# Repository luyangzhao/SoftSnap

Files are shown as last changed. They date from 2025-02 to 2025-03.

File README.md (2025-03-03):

# **SoftSnap: A Modular and Untethered Soft Robotics Platform**  

## 🚀 Overview  
SoftSnap is a **modular, untethered soft robotics system** designed for **rapid prototyping** and exploration of **bio-inspired locomotion and manipulation tasks**. It enables researchers, educators, and hobbyists to quickly assemble **snap-together robotic modules** with integrated **cable-driven actuation, onboard control, and wireless communication**.

### **🎥 Demonstration Video**  
Watch the SoftSnap in action:  
SoftSnap Video (https://www.youtube.com/watch?v=SWuYzo7xSno)

---

### **🔹 SoftSnap Full Assembly**
<!-- ![SoftSnap Full Assembly](hardware/cad/softsnap_module.png)   -->
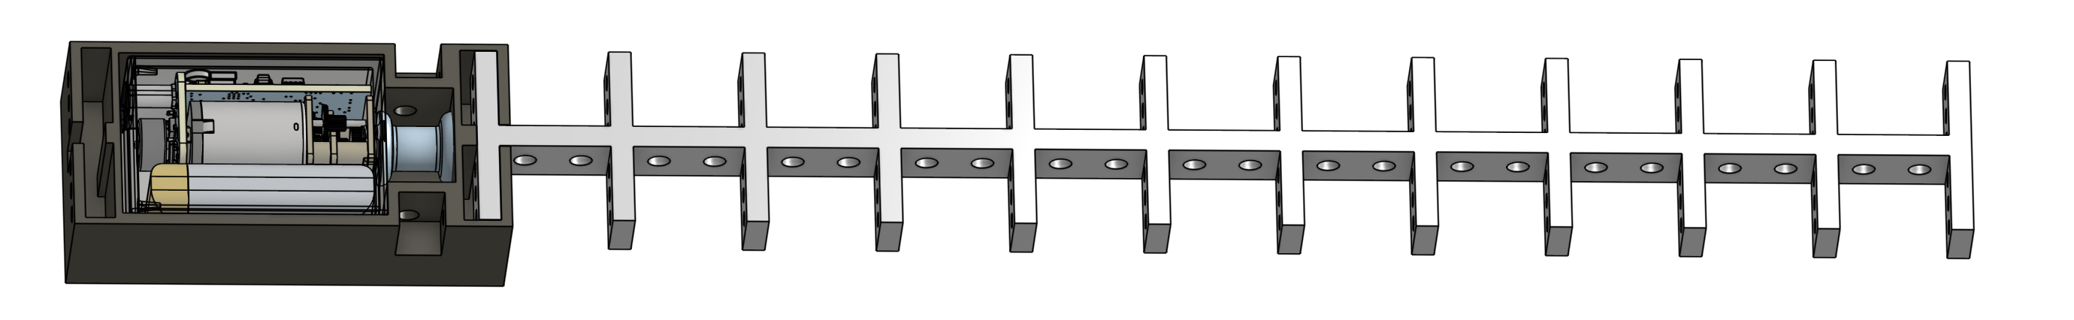
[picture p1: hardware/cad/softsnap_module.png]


### **🔹 3-in-1 Motor Module PCB**
<!-- ![SoftSnap PCB](hardware/pcb/pcb_render.png)   -->
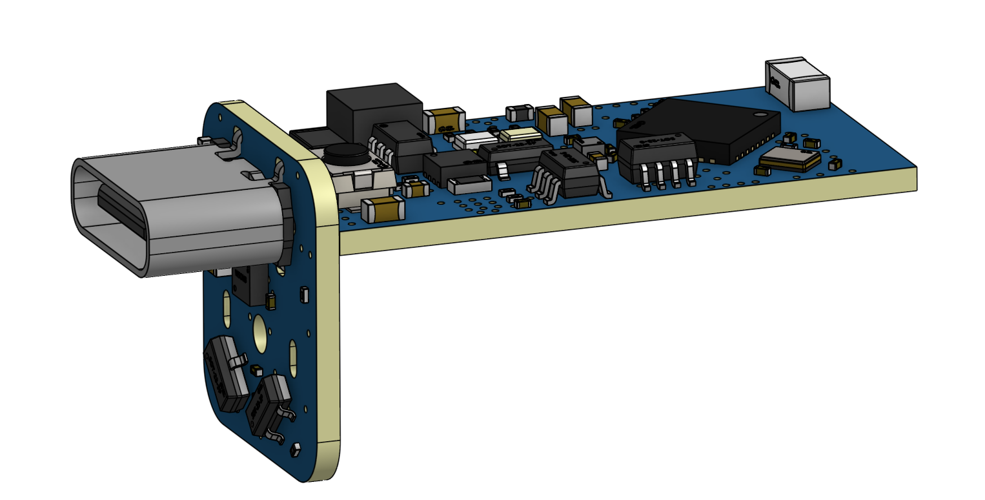
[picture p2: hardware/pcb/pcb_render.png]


---

## 📦 Open-Source Resources  
This repository provides **open-source resources**, including:  
✅ **CAD models** for SoftSnap skeletons, connectors, and casing.  
✅ **PCB designs** for the integrated control system.  
✅ **Firmware code** for the integrated control system.  
✅ **Jupyter Notebook-based code** for forward and inverse simulation.  
✅ **Assembly guidelines** to build and modify SoftSnap robots (see the video). 

---

## 🔧 Features  
- 🛠 **Modular Design**: Easily snap together different modules to create robots like starfish-inspired, brittle-star locomotion, snake-like, grippers, and ring-based caging systems.  
- 🎛 **Cable-Driven Actuation**: Uses a **motorized winch system** to control flexible TPU-based skeleton deformation.  
- 📡 **Wireless Control**: Supports remote control via **Wi-Fi-based communication**.  
- 🔄 **Open-Source & Customizable**: Modify, 3D print, and expand the system to fit specific applications.  
- 🔬 **Simulation & Modeling**: Includes Jupyter Notebook tools for **predicting deformation behavior** and optimizing threading patterns.  

---

## 📂 Repository Structure  

```
📦 SoftSnap  
 ├── hardware/                   # CAD models & PCB design  
 │   ├── pcb/                    # PCB design files  
 │   │   ├── pcb_render.png       # PCB design image  
 │   │   ├── README.md            # PCB design documentation  
 │   ├── cad/                     # 3D models and shell for 3-in-1 Motor Module  
 │   │   ├── softsnap_module.png  # Full SoftSnap module image  
 │   │   ├── README.md            # 3D model printing & assembly guide  
 ├── software/                    # Jupyter Notebook-based simulation & control code 
 │   ├── Firmware.ino             # Firmware program source code   
 │   ├── forward_simulation.ipynb # Forward kinematics simulation  
 │   ├── inverse_simulation.ipynb # Inverse kinematics simulation  
 │   ├── README.md                # Simulation documentation  
 ├── LICENSE                      # License file  
 ├── README.md                    # Main repository documentation  
```

---

## 📦 Getting Started  

### 🔩 1️⃣ Hardware Requirements  
To build a SoftSnap module, you will need:  
- **3D-printed components** (TPU skeleton, PLA connectors, resin casing)  
- **Motor module** (GA12-N20 motor, PCB, Li-ion battery)  
- **8-braid No. 2 PE fishing line** (0.23mm, 12.7 kg tensile strength)  
- **Microcontroller & Wi-Fi module** (for remote operation)  

Refer to the **assembly guide** in the `docs/` folder for detailed instructions.  

### 🖥 2️⃣ Running the Jupyter Notebook Code  
The simulation, forward and inverse modeling, and control scripts are provided as Jupyter Notebooks for ease of use.  

1. Clone this repository:  
   ```bash
   git clone https://github.com/luyangzhao/SoftSnap.git  
   cd SoftSnap
   ```  
2. Open the Jupyter Notebook:  
   ```bash
   jupyter notebook  
   ```  
3. Navigate to the **software/** directory and run the desired notebook.

---

## 🔋 Battery Life & Actuation Cycles  
The **200 mAh battery** provides a theoretical energy capacity of **0.2A × 3.7V = 0.74 Wh**. Under a nominal load, the motor consumes approximately **160 mA × 12V × 1s = 0.533 mWh** per cycle, yielding a theoretical estimate of **1,388 cycles** per full charge. However, real-world performance varies due to energy losses, standby consumption, and load fluctuations. 
<!-- Experimental testing with the **XX skeleton configuration** resulted in **XX cycles per full charge**. -->

---

## 📜 Documentation  
📄 **Paper Reference**: [SoftSnap: Rapid Prototyping of Untethered Soft Robots](https://arxiv.org/abs/2410.19169)  

📜 **CAD & PCB Files**: `/hardware/`  

💻 **Jupyter Notebook Code**: `/software/`  

🛠 **Assembly Guide & Tutorials**: `/docs/`  

🔗 **GitHub Repository**: [https://github.com/luyangzhao/SoftSnap](https://github.com/luyangzhao/SoftSnap)  

---

## 🔬 Citation  
If you use SoftSnap in your research, please cite our work:  

```
Zhao, L., Jiang, Y., She, C., Chen, M., Balkcom, D., 2024. SoftSnap: Rapid Prototyping of Untethered Soft Robots Using Snap-Together Modules. Soft Robotics. DOI: arXiv:2410.19169
```

```
@article{zhao2024softsnap,
  title={SoftSnap: Rapid prototyping of untethered soft robots using snap-together modules},
  author={Zhao, Luyang and Jiang, Yitao and She, Chun-Yi and Chen, Muhao and Balkcom, Devin},
  journal={arXiv preprint arXiv:2410.19169},
  year={2024}
}
```

---

## Help Desk

We are open and willing to answer any question. Please state your problem clearly and use the following emails to contact: Luyang Zhao: <luyang.zhao.gr@dartmouth.edu>, Yitao Jiang: <yitao.jiang.gr@dartmouth.edu>. Thank you!

---

## 📝 License  
📜 This project is licensed under the **MIT License**.

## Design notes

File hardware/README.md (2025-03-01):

# **SoftSnap Hardware: CAD Models & PCB Design**  

## 🏗️ Overview  
This folder contains **hardware-related files** for the SoftSnap modular robotics system, including **3D models (CAD)** for robot components and **PCB designs** for the control system.

---

## 📂 Folder Structure  
```
hardware/  
├── pcb/                     # PCB design files  
│   ├── pcb_render.png        # PCB design image  
│   ├── README.md             # PCB documentation & OSHWHub link  
├── cad/                     # 3D models and mechanical design  
│   ├── softsnap_module.png   # Full SoftSnap module image  
│   ├── Passive skeleton.stl  # SoftSnap passive skeleton  
│   ├── Two-directional connector.stl  # Snap-fit connector  
│   ├── 3-in-1_motor_shell_part1.stl  # Motor module shell (part 1)  
│   ├── 3-in-1_motor_shell_part2.stl  # Motor module shell (part 2)  
│   ├── README.md             # CAD printing & assembly guide  
```

---

## 🔩 **Hardware Components**  

### **1️⃣ SoftSnap Passive Skeleton**  
- A flexible TPU-based structure allowing **modular deformation**.  
- Adjustable rib lengths, thickness, and configurations for different actuation patterns.  
- File: `Passive skeleton.stl`  

### **2️⃣ 3-in-1 Motor Module Shell**  
- Protective casing for the **motor, PCB, and battery**.  
- Two-part design for easy **3D printing and assembly**.  
- Files: `3-in-1_motor_shell_part1.stl`, `3-in-1_motor_shell_part2.stl`  

### **3️⃣ Two-Directional Connector**  
- Snap-fit connector allowing **easy modular attachment** of SoftSnap components.  
- File: `Two-directional connector.stl`  

### **4️⃣ PCB Design**  
- Custom PCB for **motor control, wireless communication, and battery management**.  
- The full design is available on **OSHWHub**:  
  👉 [SoftSnap PCB Design on OSHWHub](https://oshwhub.com/cccat/universal-design)  
- File: `pcb/pcb_render.png` (preview image)  

---

## 🔧 **Modifications & Customization**  
- To **modify the mechanical design**, use the `.step` files in **Fusion 360, SolidWorks, or FreeCAD**.  
- To **adjust the PCB**, download the source files from OSHWHub.  

---

## 📜 License  
📜 This project is licensed under the **MIT License**.

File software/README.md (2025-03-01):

# **SoftSnap Simulation: Forward & Inverse Kinematics**  

## 🏗️ Overview  
This folder contains **Jupyter Notebooks** for simulating SoftSnap’s deformation behavior using **forward and inverse kinematics**. These simulations help visualize how the modular soft robot bends and actuates under different control inputs.

---

## 📂 Files in this Folder  
- `forward_simulation.ipynb` → Simulates how SoftSnap deforms given motor actuation inputs (forward kinematics).  
- `inverse_simulation.ipynb` → Computes the required control inputs to achieve a desired deformation (inverse kinematics).  
- `Firmware.ino` → The firmware program of this project. Use Arduino IDE to edit and burn into the board.  

---

## 🔧 **Installation & Setup**  
To run the simulations, you need **Python 3.x** and Jupyter Notebook installed.  

### **2️⃣ Run the Jupyter Notebook**  
Start Jupyter Notebook and open either `forward_simulation.ipynb` or `inverse_simulation.ipynb`:  
```bash
jupyter notebook
```
Then navigate to the `software/` directory and run the desired notebook.

---

## 📊 **Simulation Details**  

### **🔹 Forward Kinematics (`forward_simulation.ipynb`)**  
- Takes **motor actuation inputs** and computes the resulting deformation of SoftSnap.  
- Helps in understanding how different **threading patterns and actuation sequences** affect movement.  
- Useful for visualizing natural deformations before implementing physical actuation.  

### **🔹 Inverse Kinematics (`inverse_simulation.ipynb`)**  
- Given a **desired deformation shape**, calculates the **necessary motor inputs**.  
- Enables **path planning and motion control** for applications like gripping and locomotion.  
- Helps fine-tune actuation strategies for achieving specific robot configurations.  

---

## 🔬 **Modifications & Customization**  
- To modify simulation parameters, **adjust geometry settings** inside the notebooks.  

For additional documentation, refer to the **SoftSnap project paper**:  
📄 **[SoftSnap: Rapid Prototyping of Untethered Soft Robots](https://arxiv.org/abs/2410.19169)**  

---

## 📜 **License**  
📜 This project is licensed under the **MIT License**.

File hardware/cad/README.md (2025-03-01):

# **SoftSnap CAD Models and 3D Printing Guide**  

## 🏗️ Overview  
This folder contains **3D models** for all key components of SoftSnap, enabling modular assembly for various soft robotic configurations.  

### **🔹 Full SoftSnap Module Assembly**
SoftSnap Full Assembly  

---

## 📂 Files in this Folder  
- `3-in-1_motor_shell_part1.stl` → First part of the motor module shell.  
- `3-in-1_motor_shell_part2.stl` → Second part of the motor module shell.  
- `Passive skeleton.stl` → Passive skeleton with customizable rib structure.  
- `Two-directional connector.stl` → Snap-together connector for modular assembly.  
- `softsnap_module.png` → Rendered image of the assembled SoftSnap system.  

---

## 🔩 **Component Descriptions**  

### **1️⃣ Passive Skeleton (`Passive skeleton.stl`)**  
- A flexible structure with **adjustable rib lengths, thickness, and middle rod dimensions** for customized mechanical properties.  
- Used for deformation-based actuation in SoftSnap robots.  

**🔧 Printing Guidelines:**  
- **Material**: TPU (Flexible Filament)  
- **Layer Height**: 0.1mm for flexibility  
- **Infill**: 100% recommended for strength  
- **Print Orientation**: Flat on the print bed  
- **Cooling**: Disable cooling fans for better adhesion  

---

### **2️⃣ 3-in-1 Motor Module Shell (`3-in-1_motor_shell_part1.stl`, `3-in-1_motor_shell_part2.stl`)**  
- Houses the **motor, PCB, and battery** for untethered operation and **Wi-Fi control**.  
- Includes **USB Type-C charging support**.  

**🔧 Printing Guidelines:**  
- **Material**: PLA, ABS, or resin (for high precision)  
- **Layer Height**: 0.1mm for finer details  
- **Infill**: 20-30% for structural balance  
- **Supports**: Required for overhangs  

🔹 **For modifications**, use `3-in-1_motor_module.step` in **Fusion 360, SolidWorks, or FreeCAD**.  

---

### **3️⃣ Two-Directional Connector (`Two-directional connector.stl`)**  
- Connects the **passive skeleton** to the **motor module**.  
- Allows **easy snap-together assembly** for modular configurations.  

**🔧 Printing Guidelines:**  
- **Material**: PLA or PETG for strength  
- **Layer Height**: 0.1mm  
- **Infill**: 40% recommended  
- **Print Orientation**: Flat for best strength  

---

## 🛠️ **Assembly Instructions**  
1️⃣ Print all required **STL files** based on the printing guidelines.  
2️⃣ Assemble the **3-in-1 Motor Module** by inserting the **PCB, motor, and battery**.  
3️⃣ Attach the **passive skeleton** to the **motor module** using the **two-directional connector**.  
4️⃣ Secure the assembly using snap-fit connections.  
5️⃣ Verify alignment and test movement.  

---

## 🔧 **Modifying the CAD Models**  
- To edit the **motor module shell**, use `3-in-1_motor_module.step` in **Fusion 360, SolidWorks, or FreeCAD**.  
- To modify the **passive skeleton**, adjust the `Passive skeleton.stl` file to experiment with different rib configurations.  
- To customize the **connector**, modify `Two-directional connector.stl` to fit alternative module sizes.

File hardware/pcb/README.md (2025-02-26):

# **PCB Design for SoftSnap 3-in-1 Motor Module**  

## 🔗 Access the PCB Design  
The full **schematic, layout, and fabrication files** for the **3-in-1 Motor Module PCB** are available on **OSHWHub**:  
👉 [View the PCB Design on OSHWHub](https://oshwhub.com/cccat/universal-design)  

## 🖼️ PCB Model  
Below is the **3D-rendered PCB design** of the **3-in-1 Motor Module**:  

SoftSnap 3-in-1 Motor Module PCB  

*(If the image is not displayed, ensure `pcb_render.png` is inside the `hardware/pcb/` folder.)*  

## 🛠️ About This PCB  
This **custom PCB** integrates the **motor driver, Wi-Fi module, and power management** for the SoftSnap **3-in-1 Motor Module**.  

The PCB design process consists of **four key steps**:  
1️⃣ **Schematic Design** – Creating the circuit diagram and selecting components.  
2️⃣ **Component Layout** – Arranging components efficiently on the board.  
3️⃣ **Routing** – Connecting electrical traces to ensure proper functionality.  
4️⃣ **Final Adjustments** – Ground planes, vias, silkscreen labeling, and other optimizations.  

## 📂 How to Use  
- To **modify the PCB**, download the **KiCAD/Eagle files** from OSHWHub.  
- To manufacture the board, use the **Gerber files** provided in the OSHWHub repository.  

For **assembly instructions and wiring details**, refer to the **main SoftSnap documentation** in the `/docs/` folder.

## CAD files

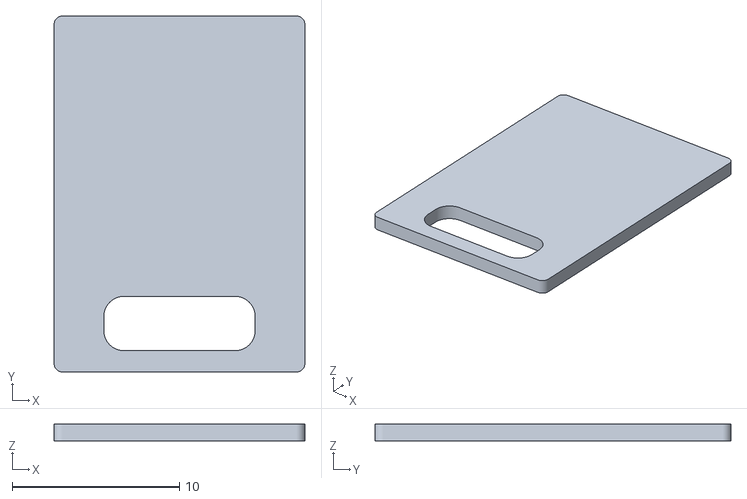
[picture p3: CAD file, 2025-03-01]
hardware/cad/3-in-1_motor_shell_part2.stl
15.0 x 21.3 x 1.00

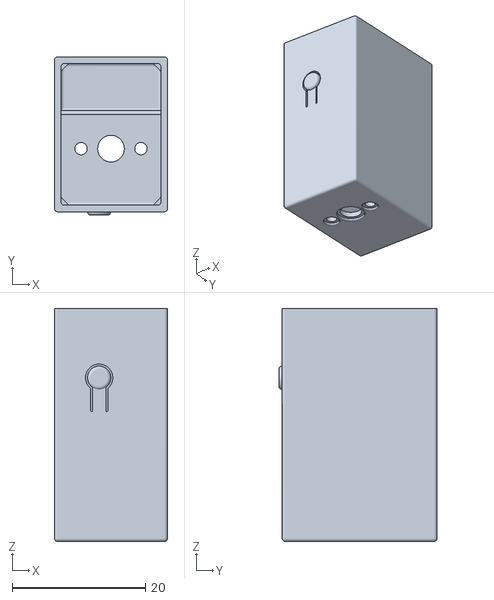
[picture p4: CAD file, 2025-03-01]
hardware/cad/3-in-1_motor_shell_part1.stl
17.0 x 23.8 x 35.0

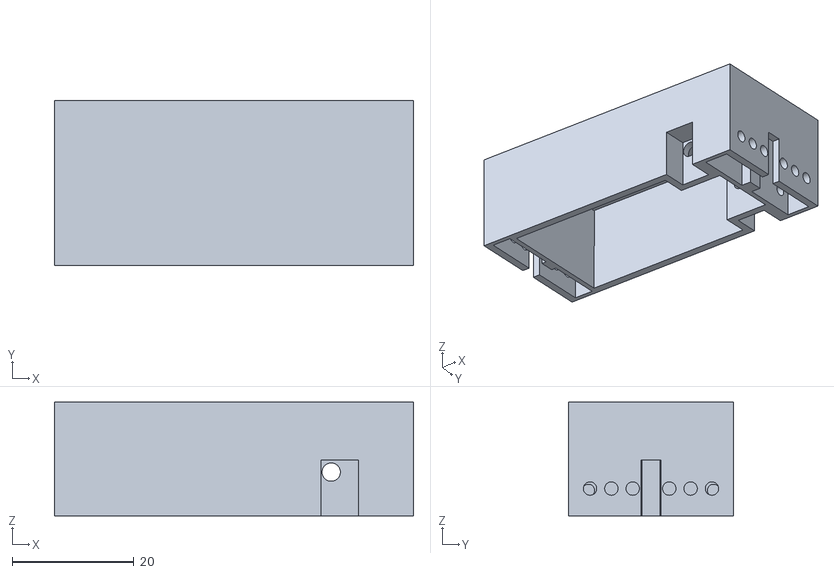
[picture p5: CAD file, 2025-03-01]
hardware/cad/Two-directional connector.stl
58.9 x 27.0 x 18.7

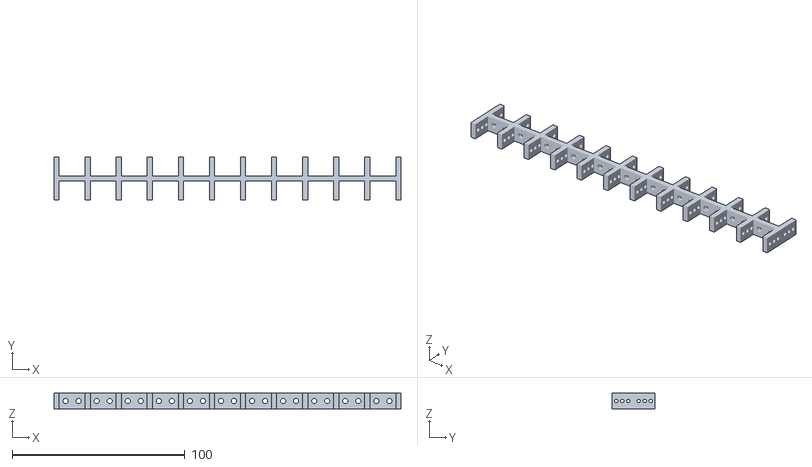
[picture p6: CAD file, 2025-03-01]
hardware/cad/Passive skeleton.stl
201.0 x 25.0 x 9.00

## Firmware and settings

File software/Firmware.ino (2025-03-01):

#include <WiFi.h>
#include <ArduinoJson.h>
#include <Wire.h>

#define INA219_ADDR 0x40

static const char *ssid = "BotTest";
static const char *password = "123456789";

// Set web server port number to 80
WiFiServer server(80);
// Variable to store the HTTP request
String header;

#define tolerance 30

#define MA 0
#define MB 1
#define MEA 6
#define MEB 7
#define OPT 8
#define LED_B 5
#define LED_G 21
#define KEY 20
#define POW_EN 10
#define SDA 3
#define SCL 4
volatile bool pause_bot = false;

volatile int32_t M_target = 0;
volatile int32_t M_current = 0;
volatile int32_t M_error = 0;
volatile uint8_t M_power = 0;

volatile uint8_t M_rec;

struct PowerData {
    float shunt_voltage;
    float bus_voltage;
    float current;
    float power;
};

volatile uint16_t VBAT_array[8] = { 0 };
volatile uint16_t VPOW_array[256] = { 0 };
volatile int vbat_index = 0;
volatile int vpow_index = 0;

uint32_t lastADCTime = 0;

void initADC() {
    Wire.begin(SDA, SCL);

    delay(10);

    // 配置INA219寄存器设置
    // BRNG = 0 (16V范围)
    // PGA = 01 (PGA = /2, ±80mV量程)
    // BADC = 1111 (12位, 128样本平均)
    // SADC = 1111 (12位, 128样本平均)
    // MODE = 111 (分流和总线连续测量)
    uint16_t config = 0b0001011111110111;
    
    Wire.beginTransmission(INA219_ADDR);
    Wire.write(0x00);
    Wire.write((config >> 8) & 0xFF);   // 高字节
    Wire.write(config & 0xFF);          // 低字节
    if (Wire.endTransmission() != 0) {
        Serial.println("Power Monitor INA219 Init - Fail");
    }
    
    // 校准寄存器设置
    // 对于15毫欧分流电阻，±80mV量程：
    // 最大电流 = 4A (80mV/15mΩ ≈ 5.33A，保守取4A)
    // Current_LSB = 4A/32768 = 122.0703125μA
    // Cal = 0.04096/(Current_LSB * RSHUNT)
    // Cal = 0.04096/(0.0001220703125 * 0.015) = 22395 (0x5775)
    uint16_t calibration = 0x5775;
    
    Wire.beginTransmission(INA219_ADDR);
    Wire.write(0x05);
    Wire.write((calibration >> 8) & 0xFF);   // 高字节
    Wire.write(calibration & 0xFF);          // 低字节
    if (Wire.endTransmission() == 0) {
        Serial.println("Power Monitor INA219 Init - Success");
    }
}

PowerData readADC() {
    PowerData data;
    uint16_t raw_value;
    
    Wire.beginTransmission(INA219_ADDR);
    Wire.write(0x02);  // 总线电压寄存器
    Wire.endTransmission();
    Wire.requestFrom(INA219_ADDR, 2);
    raw_value = Wire.read() << 8 | Wire.read();
    data.bus_voltage = (raw_value >> 3) * 0.004f;
    
    Wire.beginTransmission(INA219_ADDR);
    Wire.write(0x01);  // 分流电压寄存器
    Wire.endTransmission();
    Wire.requestFrom(INA219_ADDR, 2);
    raw_value = Wire.read() << 8 | Wire.read();
    data.shunt_voltage = raw_value * 0.00488f;  // 单位: mV (4.88μV/bit = 0.00488mV/bit)
    
    Wire.beginTransmission(INA219_ADDR);
    Wire.write(0x04);  // 电流寄存器
    Wire.endTransmission();
    Wire.requestFrom(INA219_ADDR, 2);
    raw_value = Wire.read() << 8 | Wire.read();
    data.current = raw_value * 0.1220703125f;  // 单位: mA (122.07μA/bit = 0.1220703125mA/bit)
    
    Wire.beginTransmission(INA219_ADDR);
    Wire.write(0x03);  // 功率寄存器
    Wire.endTransmission();
    Wire.requestFrom(INA219_ADDR, 2);
    raw_value = Wire.read() << 8 | Wire.read();
    data.power = raw_value * 2.44140625f;  // 单位: mW (2.44mW/bit)

    // Serial.println(data.bus_voltage);
    // Serial.println(data.shunt_voltage);
    // Serial.println(data.current);
    // Serial.println(data.power);
    return data;
}

void motor() {
  if (M_target - tolerance > M_current && !pause_bot) {
    if (M_target - tolerance * 2 > M_current) {
      digitalWrite(POW_EN, HIGH);
    }
    else if (digitalRead(POW_EN) == HIGH) {
      digitalWrite(POW_EN, LOW);
    }
    ledcWrite(MA, M_power);
    ledcWrite(MB, 0);
  } else if (M_target + tolerance < M_current && !pause_bot) {
    if (M_target + tolerance * 2 < M_current) {
      digitalWrite(POW_EN, HIGH);
    }
    else if (digitalRead(POW_EN) == HIGH) {
      digitalWrite(POW_EN, LOW);
    }
    ledcWrite(MA, 0);
    ledcWrite(MB, M_power);
  } else {
    digitalWrite(POW_EN, LOW);
    ledcWrite(MA, 0);
    ledcWrite(MB, 0);
  }
}

void IRAM_ATTR isr() {
  uint8_t M_now = (digitalRead(MEA) << 1) | digitalRead(MEB);

  // 00,01,11,10
  if ((M_rec == 0b00 && M_now == 0b01) || (M_rec == 0b01 && M_now == 0b11) || (M_rec == 0b11 && M_now == 0b10) || (M_rec == 0b10 && M_now == 0b00))
    M_current++;
  else if ((M_rec == 0b10 && M_now == 0b11) || (M_rec == 0b11 && M_now == 0b01) || (M_rec == 0b01 && M_now == 0b00) || (M_rec == 0b00 && M_now == 0b10))
    M_current--;
  else if (M_rec != M_now)
    M_error++;

  M_rec = M_now;

  motor();
}

float getBattery() {
  int temp = 0;
  for (int i = 0; i < 8; i++)
    temp += VBAT_array[i];
  return temp / 8 / 10000.0;
}

String getPower() {
  String result = "";
  for (int i = 0; i < 256; i++) {
    int index = (vpow_index + i) % 256;
    char hexStr[5];
    snprintf(hexStr, sizeof(hexStr), "%04X", VPOW_array[index]);
    result += hexStr;
  }
  return result;
}

long HexToLong(String s) {
  char arr[13] = { 0 };
  s.toCharArray(arr, sizeof(arr));
  volatile long result = 0;
  for (uint8_t i = 0; i < 12 && arr[i] != 0; i++) {
    if (arr[i] >= '0' && arr[i] <= '9') {
      result <<= 4;
      result |= (arr[i] - '0');
    } else if (arr[i] >= 'A' && arr[i] <= 'F') {
      result <<= 4;
      result |= (arr[i] - 'A' + 10);
    }
  }
  return result;
}

String inputString = "";         // 用于存储接收到的字符串

void setup() {
  digitalWrite(OPT, LOW);
  pinMode(OPT, OUTPUT);
  digitalWrite(OPT, LOW);

  Serial.begin(115200);
  Serial.println("Serial");

  delay(1000);

  pinMode(LED_B, OUTPUT);
  pinMode(LED_G, OUTPUT);
  digitalWrite(LED_B, HIGH);
  digitalWrite(LED_G, HIGH);

  Serial.println("IND Inited");

  pinMode(KEY, INPUT_PULLUP);
  Serial.println("KEY Inited");


  pinMode(POW_EN, OUTPUT);
  digitalWrite(POW_EN, LOW);

  Serial.println("POW Inited");

  ledcAttach(MA, 50000, 8);
  ledcAttach(MB, 50000, 8);
  Serial.println("LEDC Inited");

  initADC();
  Serial.println("Power Sensor Inited");

  attachInterrupt(MEA, isr, CHANGE);
  attachInterrupt(MEB, isr, CHANGE);
  pinMode(MEA, INPUT_PULLUP);
  pinMode(MEB, INPUT_PULLUP);

  M_rec = (digitalRead(MEA) << 1) | digitalRead(MEB);
  delay(500);
  digitalWrite(LED_B, LOW);

  // Connect to Wi-Fi network with SSID and password
  Serial.print("Connecting to ");
  Serial.println(ssid);
  WiFi.begin(ssid, password);
  while (WiFi.status() != WL_CONNECTED) {
    delay(500);
    Serial.print(".");
    digitalWrite(LED_B, !digitalRead(LED_B));
  }
  // Print local IP address and start web server
  Serial.println("");
  Serial.println("WiFi connected.");
  Serial.print("IP address: ");
  Serial.println(WiFi.localIP());
  Serial.print("MAC address: ");
  Serial.println(WiFi.macAddress());
  server.begin();
}

void loop() {

  uint32_t currentTime = millis();
  
  if (currentTime - lastADCTime >= 50) {
    PowerData data = readADC();
    lastADCTime = currentTime;
    for (int i=1; i<8; i++) {
      VBAT_array[i] = VBAT_array[i-1];
    }
    for (int i=1; i<256; i++) {
      VPOW_array[i] = VPOW_array[i-1];
    }
    VBAT_array[0] = data.bus_voltage * 10000;
    VPOW_array[0] = data.power * 10;
  }

  // // 检查是否有可用的串口数据
  // if (Serial.available()) {
  //   char inChar = (char)Serial.read();
    
  //   if (inChar == '\n') {
  //     // 收到换行符,处理完整的输入
  //     int number = inputString.toInt();
      
  //     Serial.print("接收到的数字是: ");
  //     Serial.println(number);
  //     M_target = (int32_t)number;
  //     M_power = (uint8_t)80;
  //     motor();
      
  //     // 在这里可以添加其他对数字的处理逻辑
      
  //     // 清空字符串,为下一次接收做准备
  //     inputString = "";
  //   } else {
  //     // 将新字符添加到输入字符串
  //     inputString += inChar;
  //   }
  // }

  WiFiClient client = server.available();  // Listen for incoming clients

  if (client) {                      // If a new client connects,
    Serial.println("New Request.");  // print a message out in the serial port
    String currentLine = "";         // make a String to hold incoming data from the client
    while (client.connected()) {     // loop while the client's connected
      if (client.available()) {      // if there's bytes to read from the client,
        char c = client.read();      // read a byte, then
        Serial.write(c);             // print it out the serial monitor
        header += c;
        if (c == '\n') {  // if the byte is a newline character
          // if the current line is blank, you got two newline characters in a row.
          // that's the end of the client HTTP request, so send a response:
          if (currentLine.length() == 0) {
            Serial.println(header);
            // HTTP headers always start with a response code (e.g. HTTP/1.1 200 OK)
            // and a content-type so the client knows what's coming, then a blank line:
            client.println("HTTP/1.1 200 OK");
            client.println("Content-type:application/json");
            client.println("Connection: close");
            client.println();

            // GET /?status HTTP/1.1
            if (header.indexOf("status") >= 0) {
              Serial.println("status requested");
              // Get the status of the system
              client.println("{\"status\":\"ok\", \"ip\":\"" + WiFi.localIP().toString() + "\", \"mac\":\"" + String(WiFi.macAddress()) + "\", \"m_current\":" + M_current + ", \"m_power\": " + M_power + ", \"m_error\": " + M_error + ", \"battery\": " + getBattery() + ", \"pause\":" + (pause_bot ? String("true") : String("false")) + ", \"power\": \"" + getPower() + "\"}");
            } else if (header.indexOf("set") >= 0) {
              Serial.println("set requested");
              // Set the target and power of motors
              // Format: `{"M1_trajectory": [[...], [...], ...], "M2_trajectory": [[...], [...], ...], "totalTime": 1000}`
              int pos = header.indexOf('=');
              String M_pos = header.substring(pos + 1, pos + 9);
              String M_pow = header.substring(pos + 9, pos + 11);
              M_target = (int32_t)HexToLong(M_pos);
              M_power = (uint8_t)HexToLong(M_pow);
              client.println("{\"status\":\"ok\", \"ip\":\"" + WiFi.localIP().toString() + "\", \"mac\":\"" + String(WiFi.macAddress()) + "\", \"m_current\":" + M_current + ", \"m_power\": " + M_power + ", \"m_error\": " + M_error + ", \"battery\": " + getBattery() + ", \"pause\":" + (pause_bot ? String("true") : String("false")) + ", \"power\": \"" + getPower() + "\"}");
            } else if (header.indexOf("calibrate") >= 0) {
              Serial.println("run requested");
              M_target = M_current = 0;
              client.println("{\"status\":\"ok\", \"ip\":\"" + WiFi.localIP().toString() + "\", \"mac\":\"" + String(WiFi.macAddress()) + "\", \"m_current\":" + M_current + ", \"m_power\": " + M_power + ", \"m_error\": " + M_error + ", \"battery\": " + getBattery() + ", \"pause\":" + (pause_bot ? String("true") : String("false")) + ", \"power\": \"" + getPower() + "\"}");
            } else if (header.indexOf("pause") >= 0) {
              Serial.println("pause requested");
              pause_bot = true;
              client.println("{\"status\":\"ok\", \"ip\":\"" + WiFi.localIP().toString() + "\", \"mac\":\"" + String(WiFi.macAddress()) + "\", \"m_current\":" + M_current + ", \"m_power\": " + M_power + ", \"m_error\": " + M_error + ", \"battery\": " + getBattery() + ", \"pause\":" + (pause_bot ? String("true") : String("false")) + ", \"power\": \"" + getPower() + "\"}");
            } else if (header.indexOf("resume") >= 0) {
              Serial.println("resume requested");
              pause_bot = false;
              client.println("{\"status\":\"ok\", \"ip\":\"" + WiFi.localIP().toString() + "\", \"mac\":\"" + String(WiFi.macAddress()) + "\", \"m_current\":" + M_current + ", \"m_power\": " + M_power + ", \"m_error\": " + M_error + ", \"battery\": " + getBattery() + ", \"pause\":" + (pause_bot ? String("true") : String("false")) + ", \"power\": \"" + getPower() + "\"}");
            } else if (header.indexOf("reach") >= 0) {
              Serial.println("resume requested");
              M_target = M_current;
              client.println("{\"status\":\"ok\", \"ip\":\"" + WiFi.localIP().toString() + "\", \"mac\":\"" + String(WiFi.macAddress()) + "\", \"m_current\":" + M_current + ", \"m_power\": " + M_power + ", \"m_error\": " + M_error + ", \"battery\": " + getBattery() + ", \"pause\":" + (pause_bot ? String("true") : String("false")) + ", \"power\": \"" + getPower() + "\"}");
            } else {
              Serial.println("error requested");
              client.println("{\"status\":\"ok\", \"ip\":\"" + WiFi.localIP().toString() + "\", \"mac\":\"" + String(WiFi.macAddress()) + "\", \"m_current\":" + M_current + ", \"m_power\": " + M_power + ", \"m_error\": " + M_error + ", \"battery\": " + getBattery() + ", \"pause\":" + (pause_bot ? String("true") : String("false")) + ", \"power\": \"" + getPower() + "\"}");
            }
            // The HTTP response ends with another blank line
            client.println();
            // Break out of the while loop
            break;
          } else {  // if you got a newline, then clear currentLine
            currentLine = "";
          }
        } else if (c != '\r') {  // if you got anything else but a carriage return character,
          currentLine += c;      // add it to the end of the currentLine
        }
      }
    }
    // Clear the header variable
    header = "";
    // Close the connection
    client.stop();
    Serial.println("Client disconnected.");
    Serial.println("");
    motor();
  }
}
